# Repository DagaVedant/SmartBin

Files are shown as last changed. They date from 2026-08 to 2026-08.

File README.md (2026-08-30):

# smartbin

a sorting head that drops into a normal trash can and puts recyclables in the right side by itself.



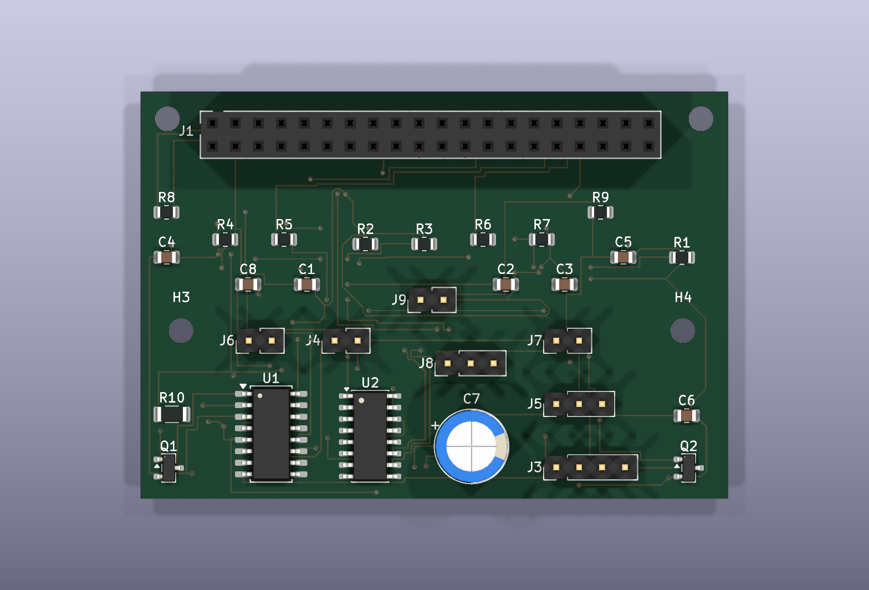
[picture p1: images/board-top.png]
board


## what it does

you throw something in. an ir beam notices, the item lands on a tilting pan, a load cell weighs it, an led ring lights it and a camera photographs it. a small neural net on a pi decides what it is, a servo tilts the pan, and the item slides into either the trash side or the recycling side.

## why

- public recycling bins get contaminated really easily
- if enough non-recyclable stuff ends up in one, the facility can reject the whole load, so all of it goes to landfill anyway
- basically every recycling project i've seen is an app that tells *you* which bin to use
- i wanted the bin to just do it, so the person doesn't have to care

## how it works

```
item dropped
   -> ir break-beam triggers
   -> item settles on the pan, load cell reads weight
   -> led ring on, camera captures, led off
   -> classifier returns one of six categories plus a confidence
   -> weight adjusts the result
   -> county rules map the category to a bin
   -> below the confidence threshold it goes to trash
   -> servo tilts, item slides, pan returns level
   -> event written to sqlite, served as json
```

two ideas drive most of the design:

**mistakes aren't symmetric.** a recyclable in the trash costs one recyclable. trash in the recycling can cost a whole load. so every uncertain decision goes to trash, enforced in two places -- a confidence gate at runtime, and a config check that refuses to start if a rules file would ever send an unidentified item to recycling.

**the pi can't sleep between items.** booting takes 20-30 seconds and an item lands in under one, so it stays awake and *idle* power dominates the whole budget. that single fact picks the board -- a zero 2 w idles at about 10 wh/day where a 4b needs about 65.

## the board

65 × 45 mm, 2 layers, 34 components, pi zero hat footprint. mounting holes on the 58 × 23 pattern; the extra 15 mm overhangs the pi.

| block | parts |
|---|---|
| load cell front end | hx711, pass transistor, feedback divider, 4 caps |
| battery sense | mcp3208 12-bit spi adc, divider, filter |
| servo rail | isolated supply, 470 uf bulk, star ground through one 0r link |
| led ring | logic-level mosfet low-side switch |
| break-beam | receiver pull-up, emitter current limit |

- **hx711 runs at 3.3 v, not 5 v.** at 5 v its logic threshold is 3.5 v and a 3.3 v gpio can't reliably hit that. running it at 3.3 v deletes 4 level-shifting parts
- **the two grounds meet at exactly one point.** a stalling servo sharing a return browns out the pi and corrupts the sd card, and it looks exactly like a software bug for hours
- **servo on gpio12, led on gpio13.** deliberately different pwm channels -- gpio12 and gpio18 are both pwm0, so the obvious pairing would've put two things needing independent duty cycles on one timer

fully routed, ground plane poured, **drc clean -- 0 violations, 0 unconnected.** gerbers in `PCB/gerber_drl_files/`.

## the mechanics

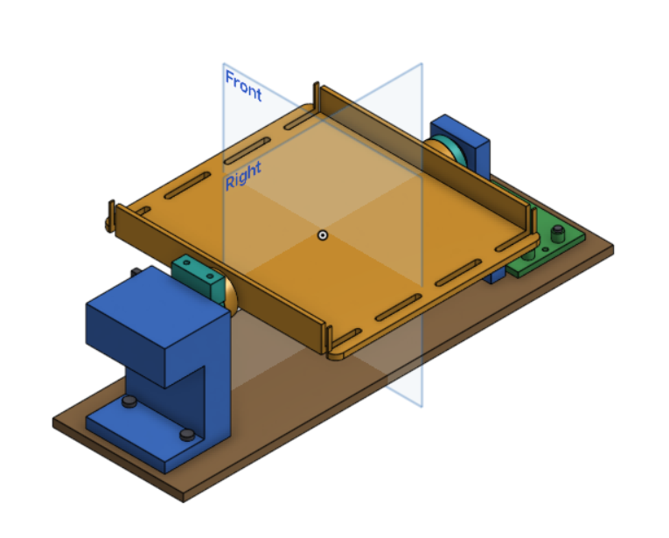
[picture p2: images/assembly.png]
assembly


7 printed parts, 21 placed instances in the assembly, 180 × 330 × 101 mm envelope.

| part | job |
|---|---|
| `base-plate` | 330 × 100 × 6 mm datum everything bolts to |
| `pan` | the tilting tray the item lands on |
| `pan-hub` | driven side, couples to the servo horn |
| `pan-idler` | free side, rides in the 608zz |
| `servo-mount` | mg996r drops into a captive pocket, shaft on the pivot axis |
| `bearing-block` | carries the 608zz on the idler side |
| `pi-mount` | pi on 6 mm standoffs, 58 × 23 pattern |

- the pivot is held at two points 206 mm apart. the base plate is what keeps them coaxial -- without it the servo's own reaction torque twists them out of line and the pivot binds
- **the pivot sits 70 mm above the plate.** not arbitrary: the pan is 180 mm wide, so at 45° its edges swing 65 mm below the axis. any lower and the pan hits the plate before it finishes tilting
- every part is a single connected solid, every joint measures a 0.00 mm gap, 0 interferences, and the pan clears everything through the full ±45° sweep with 4.9 mm spare
- the servo pocket is built around **my actual mg996r**, not the datasheet -- body measured 39.9 mm not 40.7, shaft 10.95 mm off centre not 10.35

everything around the mechanism -- the bridge carrying the camera, the throat funnel, sensor mounts, chute and enclosure -- isn't modelled yet.

`smartbin-head.step` is the whole thing as one named assembly tree, so it opens in onshape or fusion with every part listed separately. in onshape: **+ → import**, and leave "import as a single part studio" unchecked.

## the classifier

six classes: pet bottle, metal can, clean paper, organics, soiled, unknown. mobilenetv2 with a frozen backbone, exported as int8 tflite because a zero 2 w has 512 mb and no accelerator.

- **the split is by session, not by frame.** frames from one session are near-duplicates -- same lighting, same background, often the same object a few degrees rotated. split those randomly and half your test set is a near-copy of something in training, so the accuracy number is inflated and you don't find out until it's in the bin
- `evaluate.py` prints **both** numbers and the gap between them. the frame-split number is there specifically as the number not to believe
- it also prints recycle precision separately, because that's the one that matters. a recyclable in the trash costs one item. trash in the recycling can cost the whole load

```
python build_manifest.py     scan session folders -> manifest.csv
python train.py              train on the session split
python evaluate.py           honest vs naive accuracy, confusion, recycle precision
python export.py             int8 tflite for the pi
```

three dependencies: tensorflow, numpy, pillow.

## what's in here

| path | contents |
|---|---|
| `CAD/` | 7 parts as step, plus `smartbin-head.step` -- the full assembly |
| `PCB/` | kicad schematic, board and project, gerbers in `gerber_drl_files/` |
| `firmware/` | the code that runs on the pi. sort loop, rules gate, sqlite log, json api |
| `ml/` | classifier training and honest evaluation. never runs on the device |
| `images/` | board renders and the assembly |
| `bill_of_materials.csv` | every part needed to build one |

## where it's at

| thing | status |
|---|---|
| schematic | 34 components, 26 nets, connectivity verified against the netlist |
| board | routed, plane poured, **drc clean** |
| gerbers | exported |
| cad | 7 parts, 0 interferences, pan clears ±45° |
| firmware | 8 modules. trigger, weigh, capture, classify, gate, actuate, log, json api |
| ml pipeline | 6 modules, tensorflow only. manifest, session split, train, evaluate, int8 export |
| classifier | not trained. no dataset collected |

every number above comes from kicad's drc and erc, and from interference and swept-collision checks on the cad.

## known unknown

the pan tilt angle is 45 deg because that was the starting guess. nobody has confirmed that a wet or crumpled piece of paper actually slides off printed petg at that angle, and every part downstream of the pan depends on it. that is the first thing to test.

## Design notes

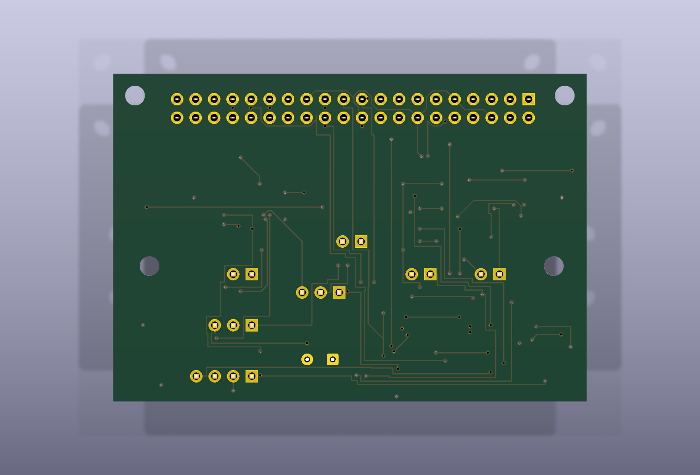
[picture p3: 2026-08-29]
images/board-bottom.png

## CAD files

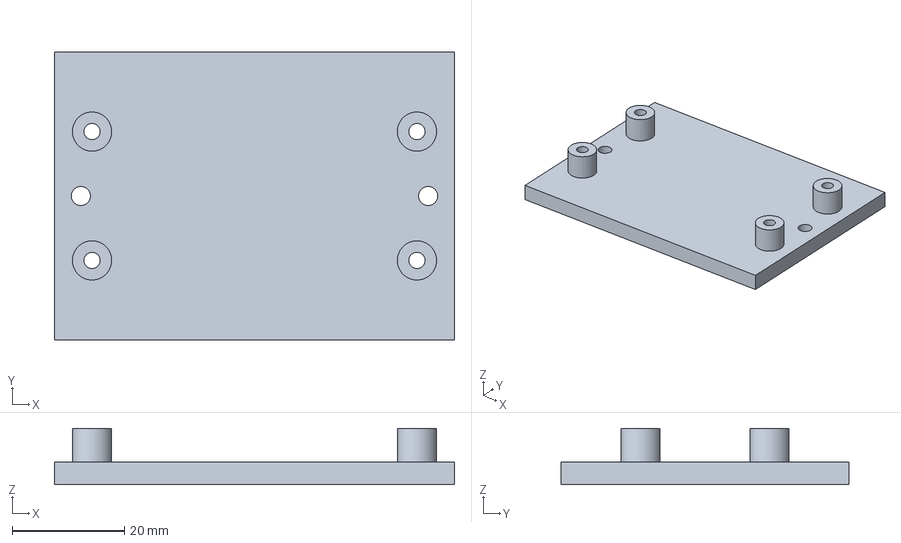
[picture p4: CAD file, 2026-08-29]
CAD/pi-mount-v1.step
71.4 x 51.4 x 10.0 mm

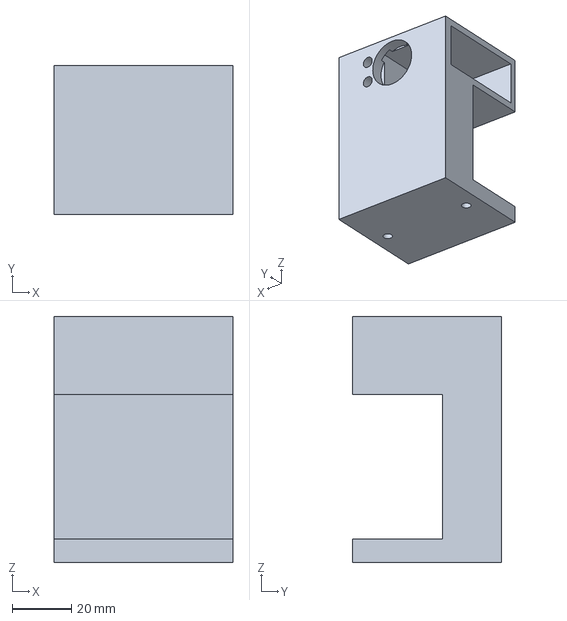
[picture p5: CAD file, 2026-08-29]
CAD/servo-mount-v1.step
60.4 x 50.4 x 83.2 mm

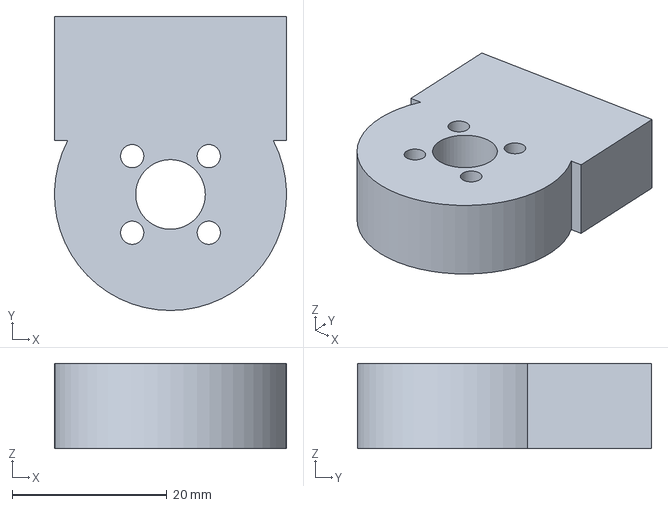
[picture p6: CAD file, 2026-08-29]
CAD/pan-hub-v1.step
30.0 x 38.0 x 11.0 mm

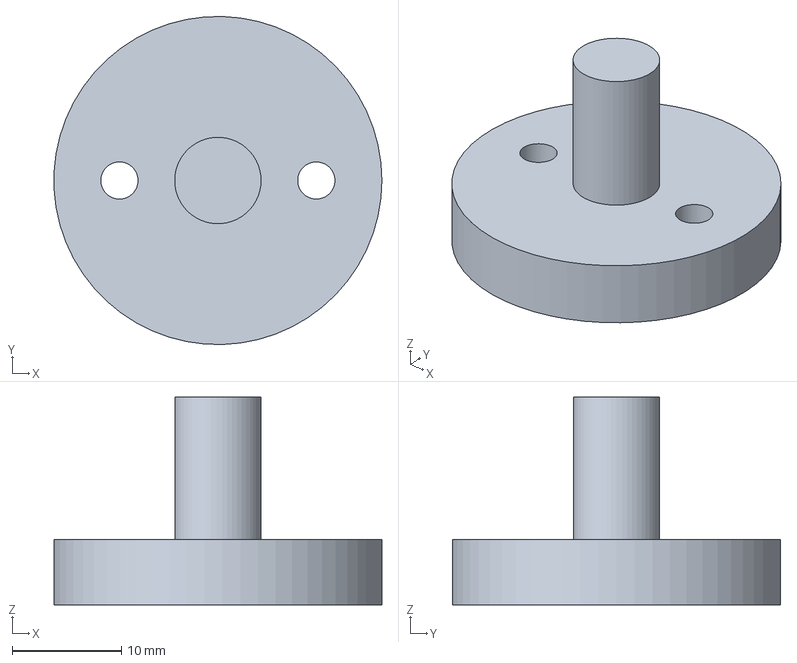
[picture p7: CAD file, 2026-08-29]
CAD/pan-idler-v1.step
30.0 x 30.0 x 19.0 mm

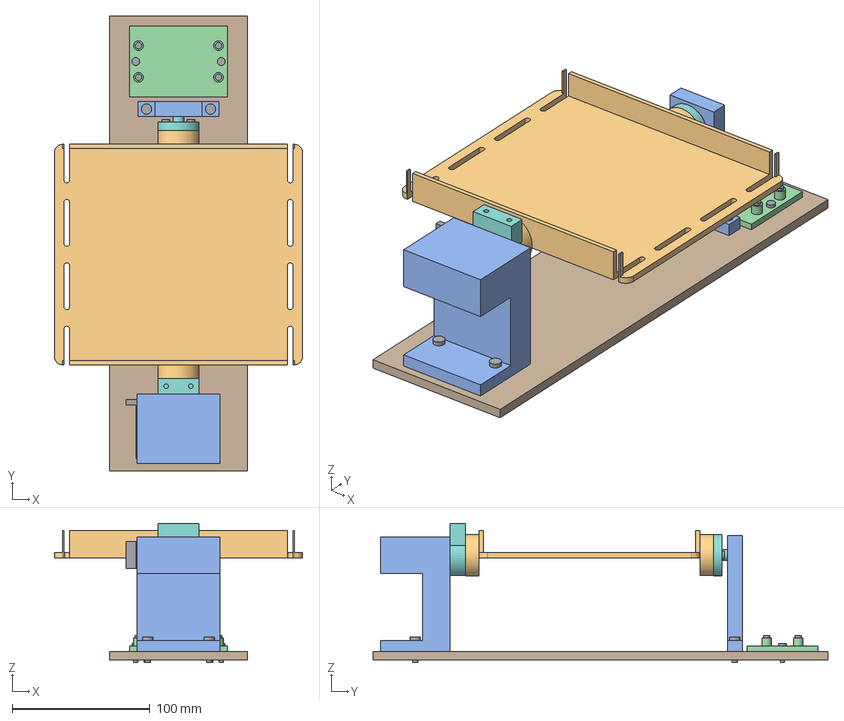
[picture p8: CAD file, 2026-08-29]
CAD/smartbin-head.step
180.0 x 330.0 x 101.0 mm
base-plate
pan
pan-hub
pan-idler
bearing-block
servo-mount
pi-mount
bearing-608
servo
idler-screw-left
idler-screw-right
bearing-screw-left
bearing-screw-right
servo-screw-left
servo-screw-right
pi-base-screw-left
pi-base-screw-right
pi-screw-a
pi-screw-b
pi-screw-c
pi-screw-d

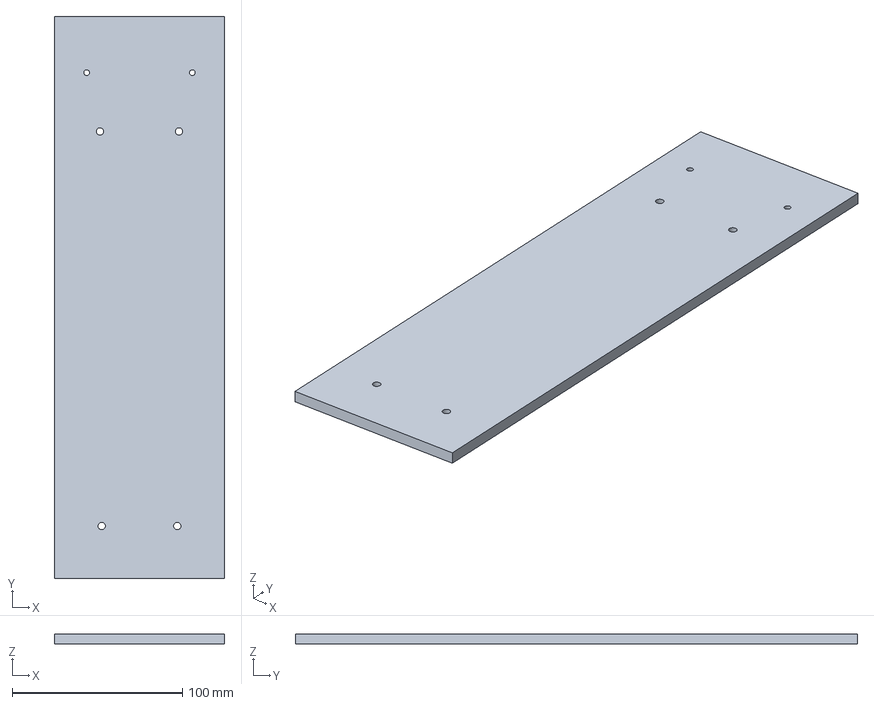
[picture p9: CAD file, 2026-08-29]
CAD/base-plate-v1.step
100.0 x 330.0 x 6.00 mm

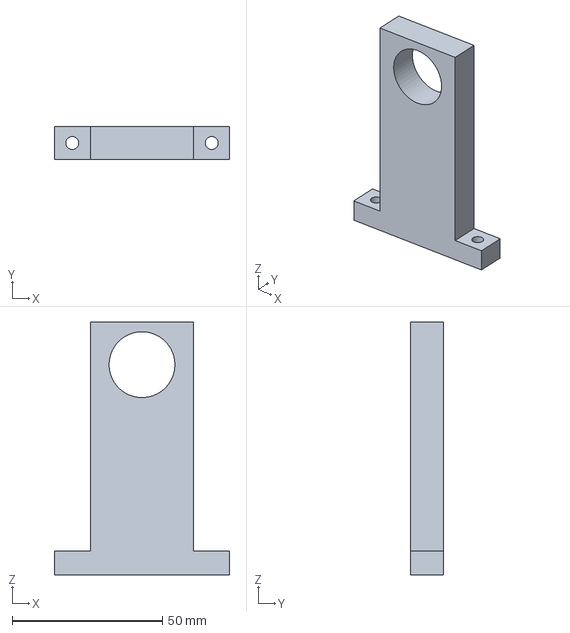
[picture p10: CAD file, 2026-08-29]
CAD/bearing-block-v1.step
58.4 x 11.0 x 84.2 mm

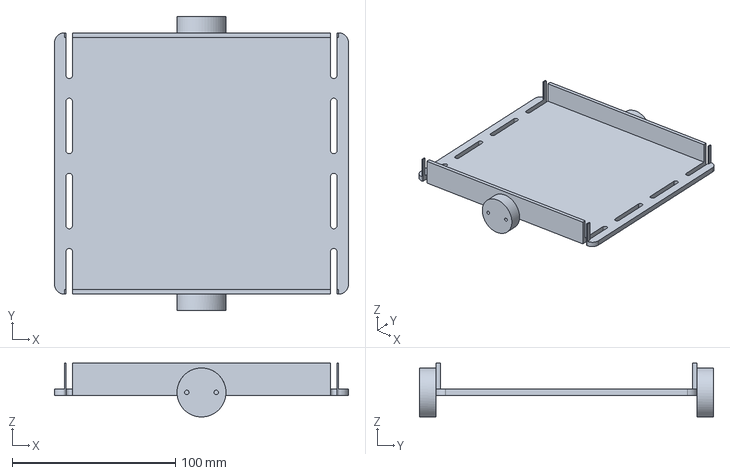
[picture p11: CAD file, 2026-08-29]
CAD/pan-v1.step
180.0 x 180.0 x 33.0 mm

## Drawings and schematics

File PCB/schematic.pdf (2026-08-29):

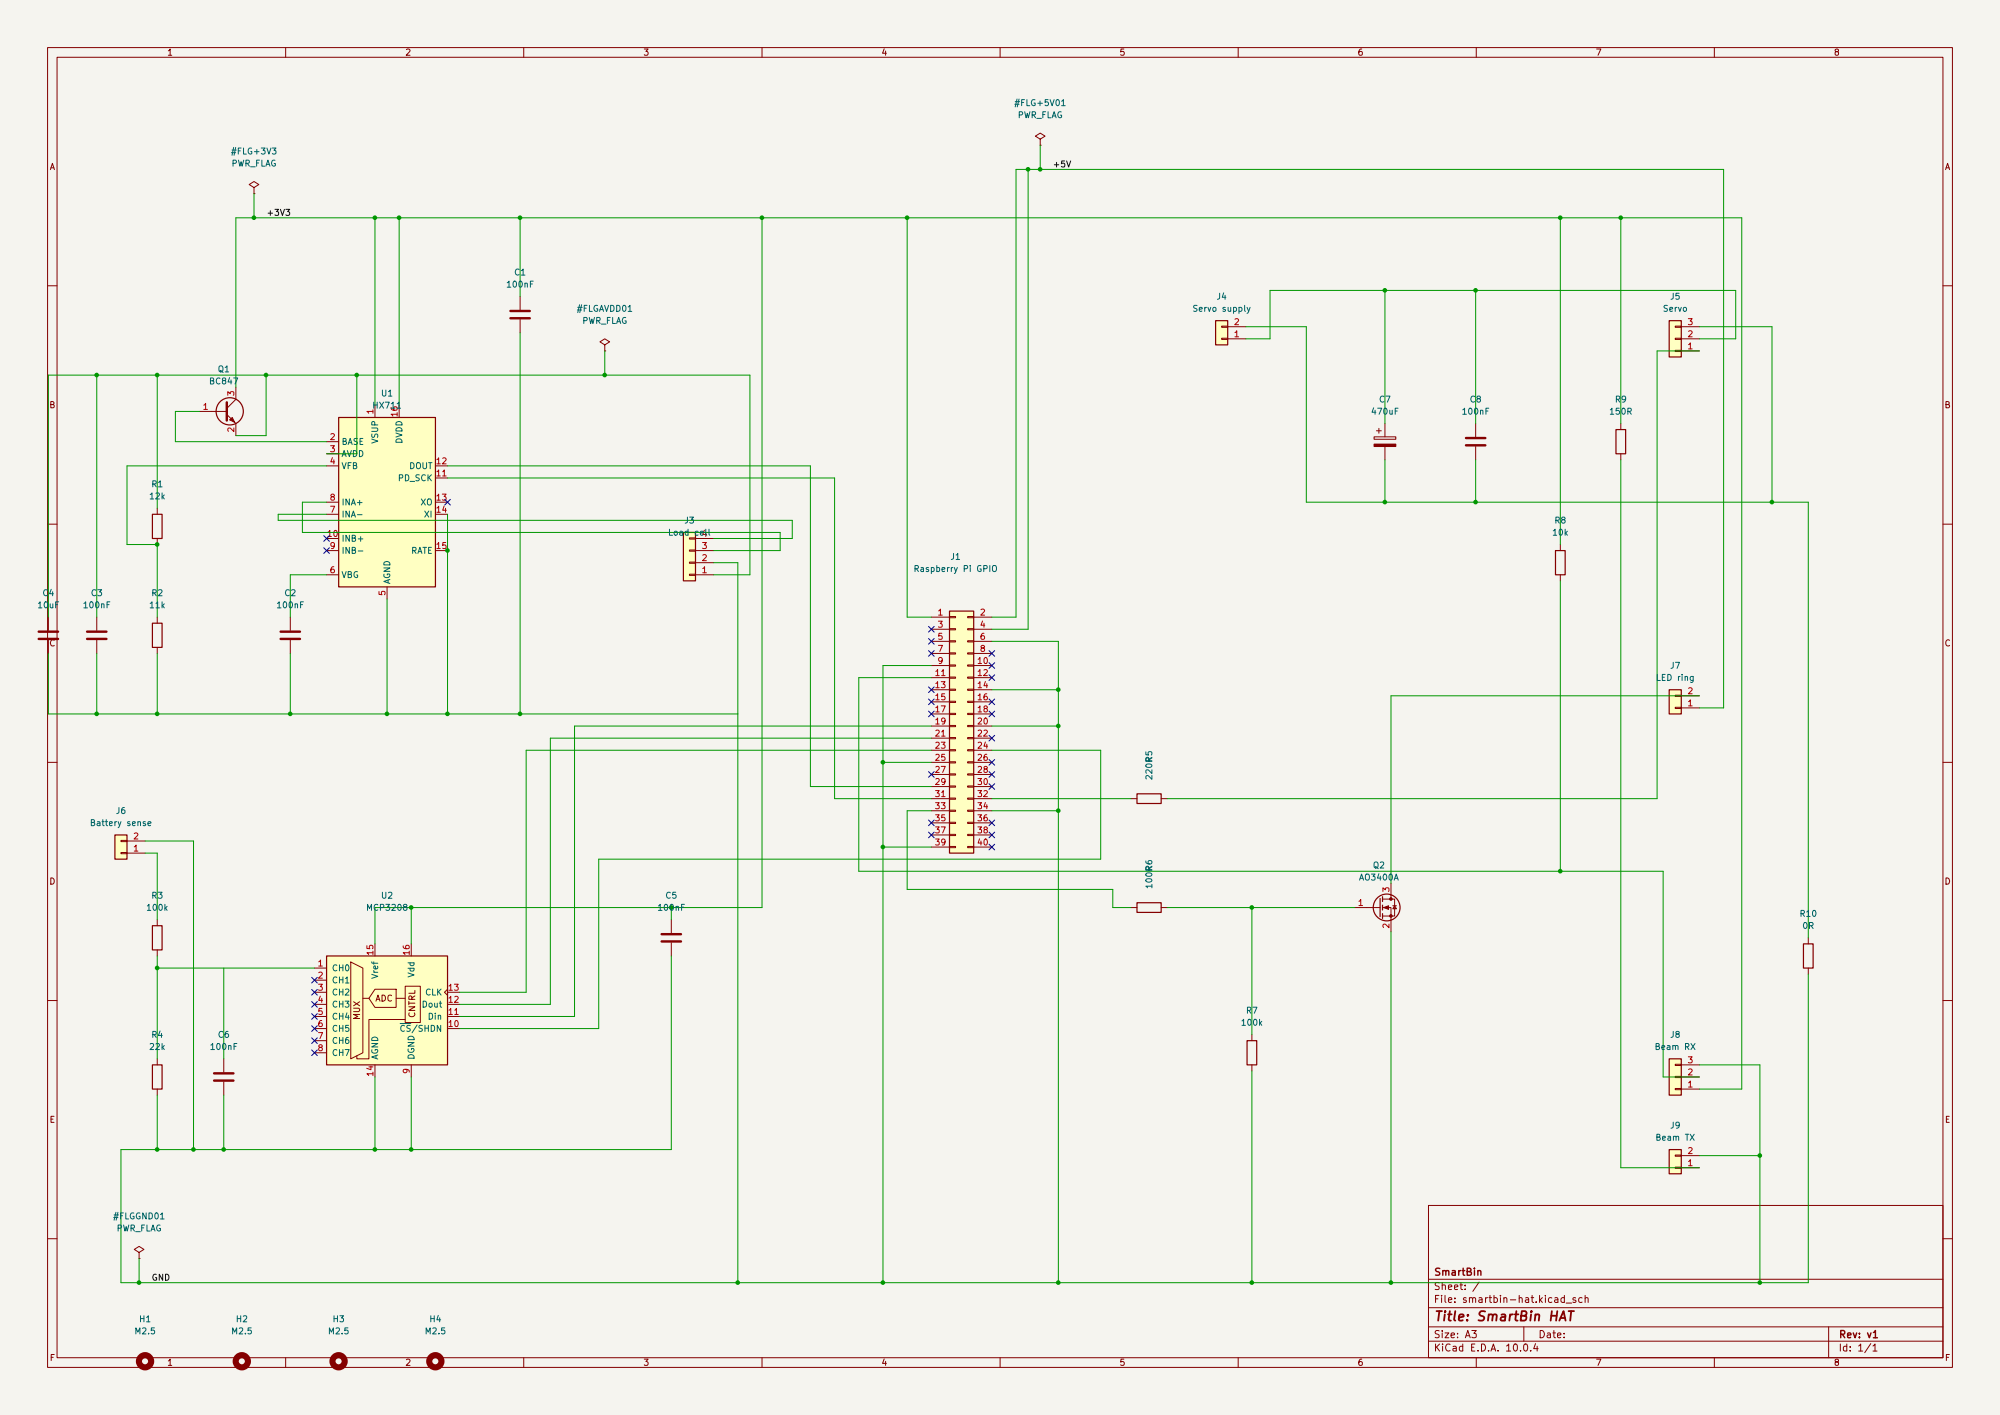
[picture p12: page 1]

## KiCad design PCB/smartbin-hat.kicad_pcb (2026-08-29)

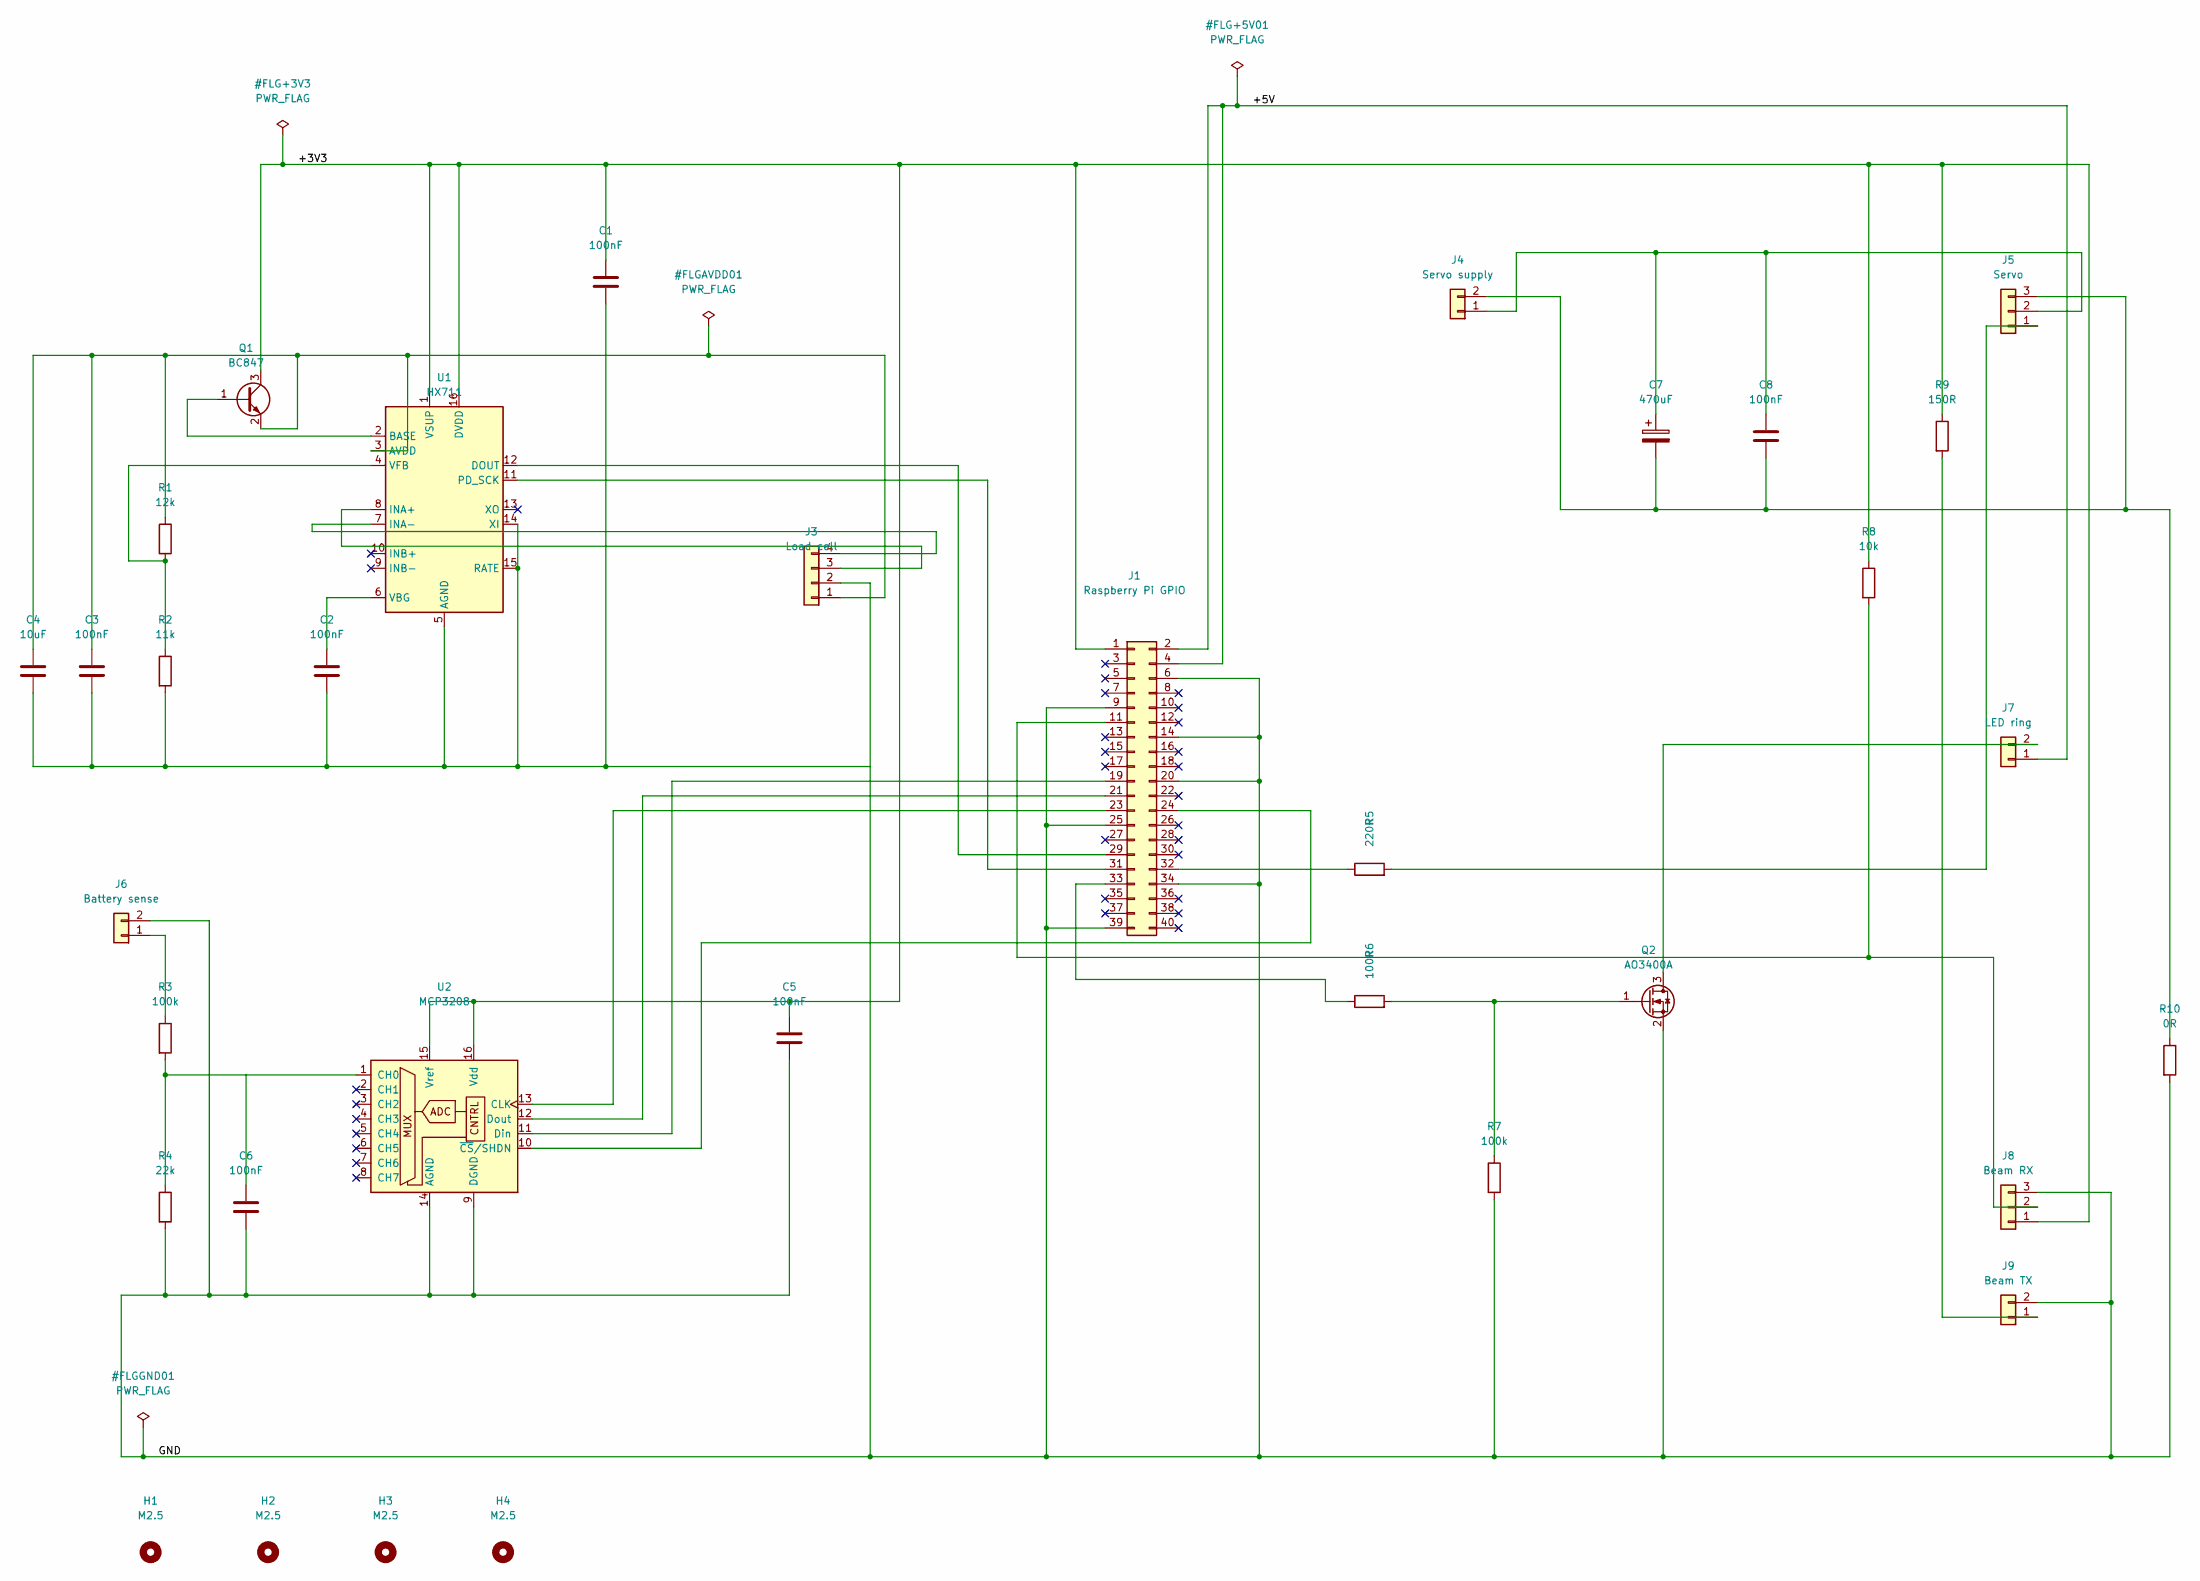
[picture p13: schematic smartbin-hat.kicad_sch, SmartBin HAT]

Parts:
C1, C2, C3, C5, C6, C8: 100nF; C_0805_2012Metric
C4: 10uF; C_0805_2012Metric
C7: 470uF; CP_Radial_D8.0mm_P3.50mm
H1, H2, H3, H4: M2.5; MountingHole_2.7mm_M2.5
J1: Raspberry Pi GPIO; PinSocket_2x20_P2.54mm_Vertical
J3: Load cell; PinHeader_1x04_P2.54mm_Vertical
J4: Servo supply; PinHeader_1x02_P2.54mm_Vertical
J5: Servo; PinHeader_1x03_P2.54mm_Vertical
J6: Battery sense; PinHeader_1x02_P2.54mm_Vertical
J7: LED ring; PinHeader_1x02_P2.54mm_Vertical
J8: Beam RX; PinHeader_1x03_P2.54mm_Vertical
J9: Beam TX; PinHeader_1x02_P2.54mm_Vertical
Q1: BC847; SOT-23
Q2: AO3400A; SOT-23
R1: 12k; R_0805_2012Metric
R2: 11k; R_0805_2012Metric
R3, R7: 100k; R_0805_2012Metric
R4: 22k; R_0805_2012Metric
R5: 220R; R_0805_2012Metric
R6: 100R; R_0805_2012Metric
R8: 10k; R_0805_2012Metric
R9: 150R; R_0805_2012Metric
R10: 0R; R_1206_3216Metric
U1: HX711; SOP-16_4.4x10.4mm_P1.27mm
U2: MCP3208; SOIC-16_3.9x9.9mm_P1.27mm

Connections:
+3V3: C1.1, C5.1, J1.1, J8.1, Q1.3 (C), R8.1, R9.1, U1.1 (VSUP), U1.16 (DVDD), U2.15 (Vref), U2.16 (Vdd)
+5V: J1.2, J1.4, J7.1
AVDD: C3.1, C4.1, J3.1, Q1.2 (E), R1.1, U1.3 (AVDD)
AVDD_BASE: Q1.1 (B), U1.2 (BASE)
AVDD_FB: R1.2, R2.1, U1.4 (VFB)
BEAM_RX: J1.11, J8.2, R8.2
BEAM_TX_A: J9.1, R9.2
CELL_A+: J3.3, U1.8 (INA+)
CELL_A-: J3.4, U1.7 (INA-)
GND: C1.2, C2.2, C3.2, C4.2, C5.2, C6.2, J1.6, J1.9, J1.14, J1.20, J1.25, J1.34, J1.39, J3.2, J6.2, J8.3, J9.2, Q2.2 (S), R2.2, R4.2, R7.2, R10.2, U1.5 (AGND), U1.14 (XI), U1.15 (RATE), U2.9 (DGND), U2.14 (AGND)
GND_SERVO: C7.2, C8.2, J4.2, J5.3, R10.1
HX_DOUT: J1.29, U1.12 (DOUT)
HX_SCK: J1.31, U1.11 (PD_SCK)
LED_CATHODE: J7.2, Q2.3 (D)
LED_GATE: Q2.1 (G), R6.2, R7.1
LED_PWM: J1.33, R6.1
SERVO_SIG: J1.32, R5.1
SERVO_SIG_OUT: J5.1, R5.2
SPI_CE0: J1.24, U2.10 (~CS/SHDN)
SPI_MISO: J1.21, U2.12 (Dout)
SPI_MOSI: J1.19, U2.11 (Din)
SPI_SCLK: J1.23, U2.13 (CLK)
VBATT: J6.1, R3.1
VBG: C2.1, U1.6 (VBG)
VSERVO: C7.1, C8.1, J4.1, J5.2

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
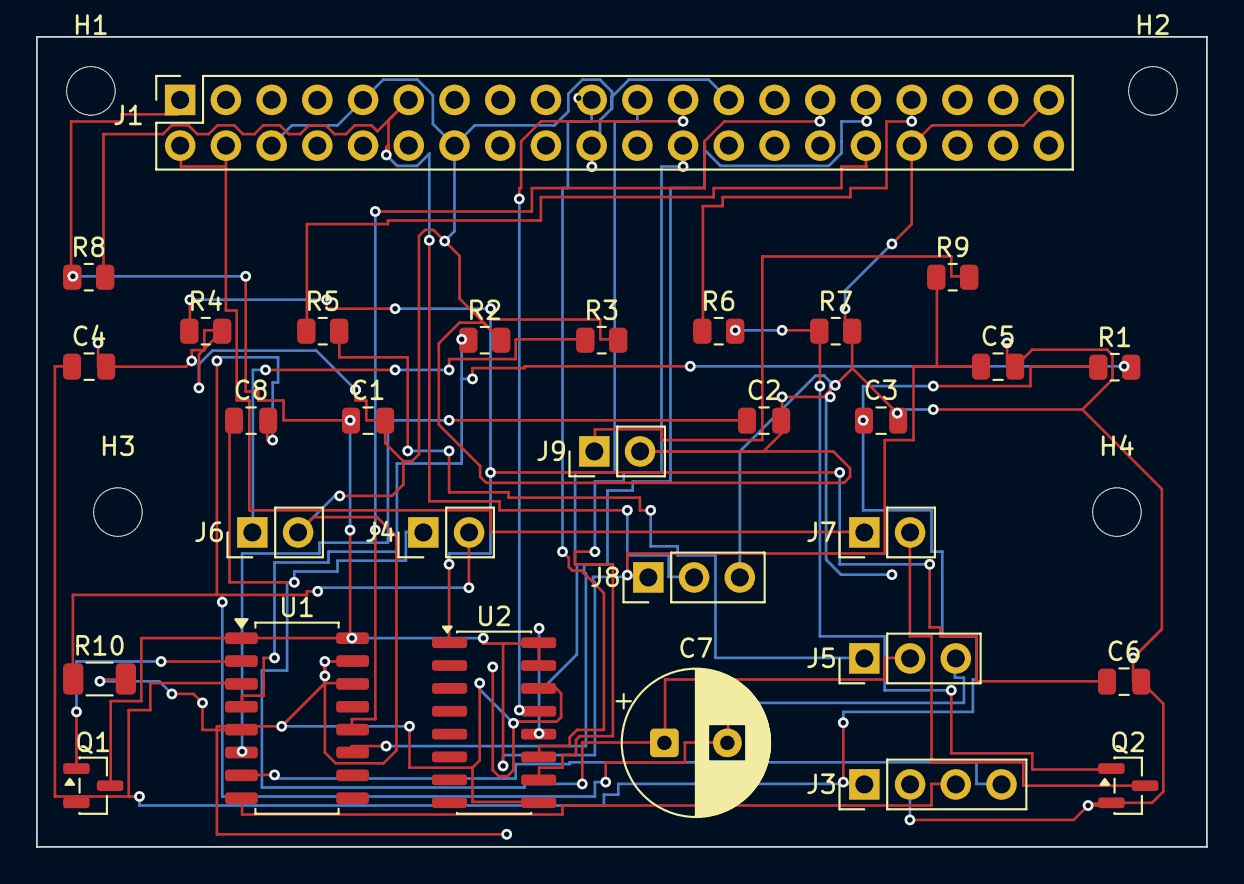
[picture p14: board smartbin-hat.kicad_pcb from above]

Board: 2 copper layers, 65.0 x 45.0 mm, 34 parts (0 on the bottom side), 26 nets.

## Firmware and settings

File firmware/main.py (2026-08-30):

import argparse
import signal
import sys
import time

import api
import rules
import storage
from classifier import Classifier
from hardware import Hardware

running = True


def stop(signum, frame):
    global running
    running = False


def sort_once(config, device, model, db):
    device.wait_for_item()
    time.sleep(config["settle_seconds"])

    weight = device.read_weight()

    device.light(True)
    image = device.capture()
    device.light(False)

    label, confidence = model.predict(image)
    bin_name, reason = rules.decide(config, label, confidence, weight)

    device.tilt(bin_name)
    device.level()

    storage.log_event(db, label, confidence, weight, bin_name, reason)
    print(label, round(confidence, 3), str(round(weight, 1)) + "g", "->", bin_name, "(" + reason + ")")
    return bin_name


def main():
    parser = argparse.ArgumentParser()
    parser.add_argument("--config", default="config.json")
    parser.add_argument("--once", action="store_true")
    args = parser.parse_args()

    config = rules.load(args.config)

    device = Hardware(config)
    model = Classifier(config["model"])
    db = storage.open_db(config["database"])

    api.serve(db, config["api_port"])

    print("api on port", config["api_port"])
    print("threshold:", config["confidence_threshold"], "| anything below goes to trash")

    signal.signal(signal.SIGINT, stop)
    signal.signal(signal.SIGTERM, stop)

    try:
        while running:
            sort_once(config, device, model, db)
            if args.once:
                break
    finally:
        device.close()
        db.close()
        print("stopped")

    return 0


if __name__ == "__main__":
    sys.exit(main())

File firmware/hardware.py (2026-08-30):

import time

from gpiozero import AngularServo, DigitalInputDevice, DigitalOutputDevice, PWMLED
from picamera2 import Picamera2


class Hardware:
    def __init__(self, config):
        self.config = config
        pins = config["pins"]

        self.beam = DigitalInputDevice(pins["beam"], pull_up=True)
        self.led = PWMLED(pins["led"])
        self.servo = AngularServo(pins["servo"], min_angle=-90, max_angle=90)
        self.data = DigitalInputDevice(pins["hx711_data"])
        self.clock = DigitalOutputDevice(pins["hx711_clock"])

        self.camera = Picamera2()
        self.camera.configure(self.camera.create_still_configuration())
        self.camera.start()

        self.level()

    def wait_for_item(self):
        self.beam.wait_for_inactive()
        self.beam.wait_for_active()

    def read_raw(self):
        while self.data.value:
            time.sleep(0.001)

        value = 0
        for _ in range(24):
            self.clock.on()
            value = (value << 1) | self.data.value
            self.clock.off()

        self.clock.on()
        self.clock.off()

        if value & 0x800000:
            value -= 0x1000000
        return value

    def read_weight(self):
        samples = sorted(self.read_raw() for _ in range(11))
        median = samples[len(samples) // 2]
        cell = self.config["load_cell"]
        return (median - cell["offset"]) / cell["scale"]

    def light(self, on):
        self.led.value = 1.0 if on else 0.0

    def capture(self):
        return self.camera.capture_array()

    def tilt(self, bin_name):
        angle = self.config["tilt_angle_deg"]
        self.servo.angle = angle if bin_name == "recycle" else -angle
        time.sleep(self.config["tilt_hold_seconds"])

    def level(self):
        self.servo.angle = 0
        time.sleep(0.4)

    def close(self):
        self.light(False)
        self.level()
        self.camera.stop()

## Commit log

2026-08-27 adding PCB and CAD files
    [bearing-block-v1.step, bearing-block-v1.stl, bom.csv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]
2026-08-29 routing the PCB and schematic (save meee it takes so long) + attached gerber, drl, and the kicad files
    [bom.csv, cleanstream-hat.kicad_pcb, cleanstream-hat.kicad_sch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]
2026-08-29 added all the cad files
    [base-plate-v1.step, bearing-block-v1.step, bearing-block-v1.stl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]
2026-08-29 added images of the PCB, updating the gitignore, and removing README.md till i fix it
2026-08-30 update readme, add assembly render
2026-08-30 add the bom. prices and links still to fill in
2026-08-31 updated pcb files + added links to all the parts in the BOM
2026-08-31 updated the BOM
2026-08-31 updated BOM even more
2026-08-31 was able to cut prices
2026-08-31 updating the BOM again
2026-09-16 Re-source 9 BOM parts from Amazon to AliExpress to cut cost
2026-09-16 updated BOM and looked for better deals
2026-09-16 removed LED strip cuz it aint neccesary
2026-11-02 updating the CAD models to be the newer ones
2026-11-02 update gerbers
2026-11-02 update BOM: pi zero w and mg90s are owned, drop break-beam and horn
2026-11-02 Simplify README by removing CAD details and repo layout
    Removed detailed descriptions of CAD parts and repository layout.
